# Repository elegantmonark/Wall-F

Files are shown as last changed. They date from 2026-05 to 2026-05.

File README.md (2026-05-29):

# WALL-F Waste Sorting Robot

<div align="center">

**Autonomous waste-sorting robot built for the UNSW DESN1000 ELEC stream.**

PixyCam vision | Arduino control | RGB sorting | Differential drive | Servo clamp

**2nd place out of 30 teams** with **16 successful deposits in 10 minutes**, all in the correct RGB order, earning a **High Distinction**.

[Algorithm](waste-sorting-algorithm.md) | [Wiring](wiring.md) | [Design Process](design-process.md) | [Final Report](documentation/ELEC_FinalReport_TeamC1.pdf)

</div>

## At A Glance

| Area | Details |
| --- | --- |
| Competition | UNSW DESN1000 ELEC waste-sorting robot challenge |
| Result | 2nd out of 30 teams, 16 deposits in 10 minutes, High Distinction |
| Control | Arduino-based autonomous control loop |
| Sensing | PixyCam 2.1 vision, ultrasonic obstacle sensing, IR clamp confirmation |
| Actuation | Differential drive, dual-servo clamp, deposit/reverse cycle |
| Documentation | Final report, design proposal, design journals, wiring, algorithm, calibration sketches |

## Overview

WALL-F is an autonomous waste-sorting robot designed to identify, collect, and deposit coloured balls representing different plastic waste categories inside a competition arena. The robot logs its home base colour, searches for red, green, and blue target balls in sequence, captures each ball with a front clamp, returns to base, deposits it, and repeats the cycle.

The final build used a two-level PLA chassis, a removable WALL-E-inspired shell, a PixyCam 2.1 for colour tracking, an ultrasonic sensor for obstacle detection, and an IR sensor inside the clamp for capture confirmation.

## Final Build

| Competition build | Internal layout |
| --- | --- |
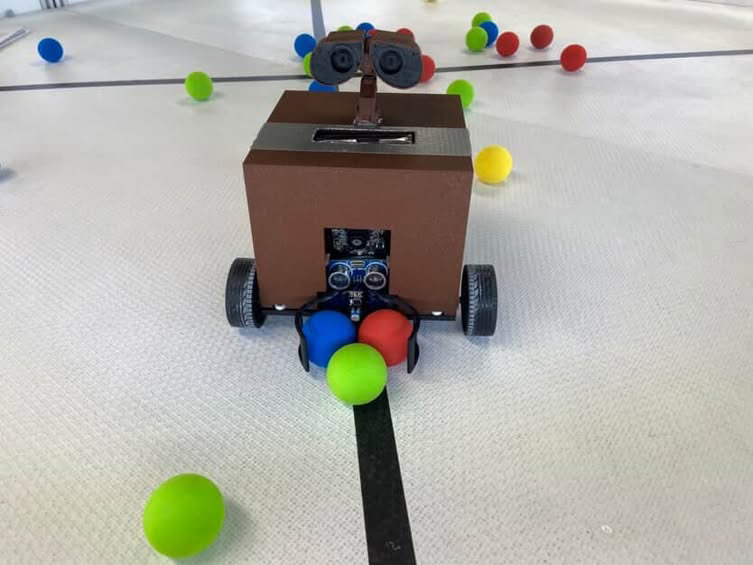
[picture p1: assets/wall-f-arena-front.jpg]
Completed WALL-F in the arena
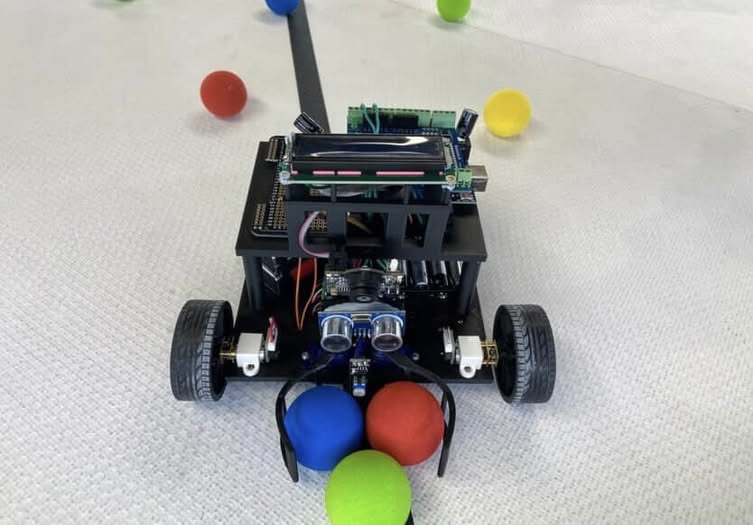
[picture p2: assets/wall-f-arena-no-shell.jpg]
WALL-F without shell showing internal layout
|  |  |

| Full assembly render | No-shell chassis |
| --- | --- |
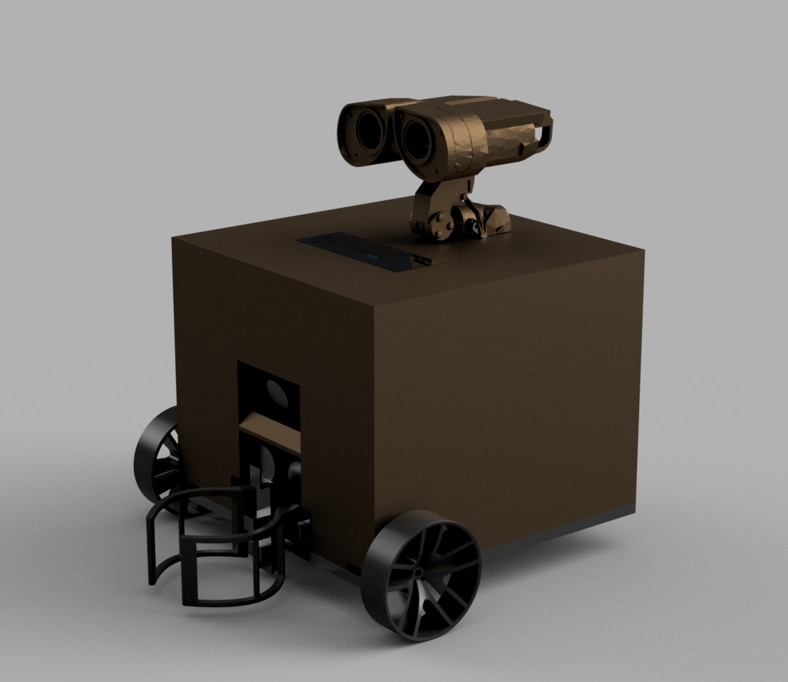
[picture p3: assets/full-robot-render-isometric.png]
WALL-F concept render
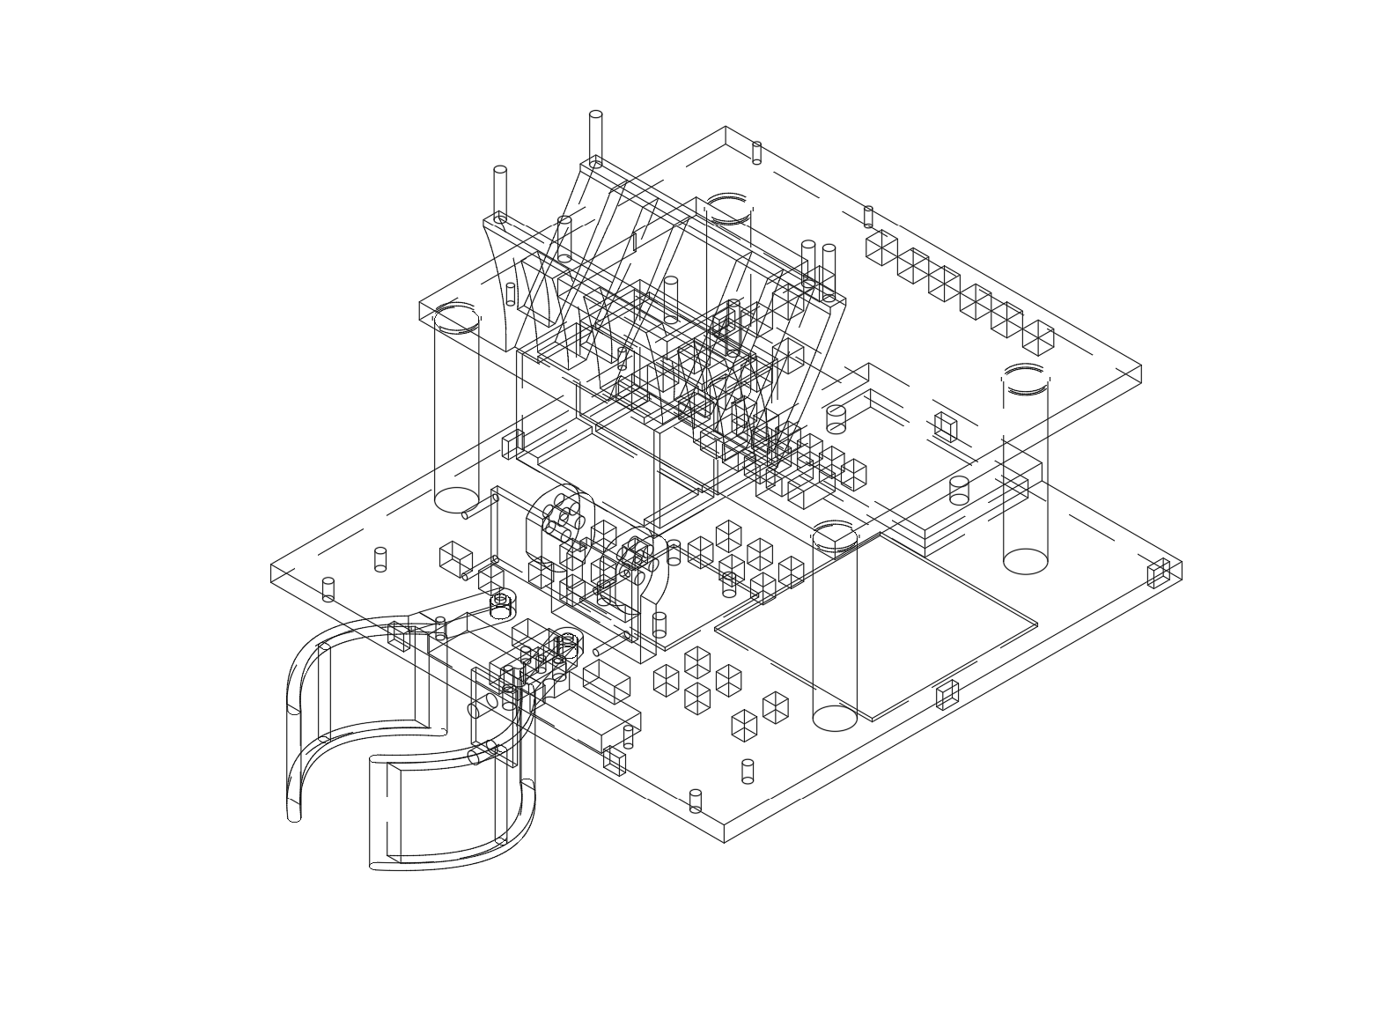
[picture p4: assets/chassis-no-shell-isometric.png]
No-shell isometric chassis model
|  |  |

## What It Does

```text
Log base -> search target -> centre -> chase -> clamp -> return -> deposit -> repeat
```

WALL-F sorts balls in strict RGB order:

```text
RED -> GREEN -> BLUE -> repeat
```

| Subsystem | Role |
| --- | --- |
| Vision | PixyCam 2.1 tracks coloured balls and home-base plates |
| Drive | Differential-drive DC motors execute calibrated movement and turning |
| Obstacle handling | HC-SR04 ultrasonic sensor detects nearby walls and obstacles |
| Capture | Dual FS90MG servos close the front clamp around a detected ball |
| Confirmation | TCRT5000 IR sensor confirms when a ball is inside the clamp |
| Deposit | Robot returns to the logged base colour, opens the clamp, reverses, and continues |

See [waste-sorting-algorithm.md](waste-sorting-algorithm.md) for the full algorithm breakdown.

## Competition Outcome

| Metric | Outcome |
| --- | --- |
| Placement | 2nd out of 30 teams |
| Deposits | 16 successful ball deposits |
| Run time | 10 minutes |
| Sequence | Correct RGB order |
| Course result | High Distinction |

## Engineering Highlights

- Built around repeated autonomous collection cycles rather than a single scripted run.
- Used PixyCam colour signatures for both target-ball tracking and home-base return.
- Combined proportional visual chasing with timed motor calibration for arena navigation.
- Integrated ultrasonic obstacle handling so the robot could recover from nearby walls.
- Used an IR-confirmed servo clamp so the robot only transitioned after a real capture.
- Debugged electrical integration issues including servo jitter caused by intermittent common-ground connection.
- Finalised an integrated RGB sequence algorithm that performed reliably during competition testing.

## Design Evolution

The design moved from early ball-retrieval concepts to a compact WALL-F gripper robot through concept scoring, mechanical iteration, sensor testing, and final integration.

Key decisions included:

- selecting a servo-actuated clamp over passive scoop and bell-enclosure concepts
- choosing a two-front-wheel and rear-caster layout for simpler turning
- separating the internal drive/sensor chassis from the removable external shell
- validating PixyCam signatures before full mechanical integration
- adding calibration sketches for motors, servos, ultrasonic sensing, IR sensing, and base return

See [design-process.md](design-process.md) for a compact public summary of the proposal, journals, and final design iteration.

## Electrical Schematic

The final circuit schematic is included as both a PNG preview and PDF exports.

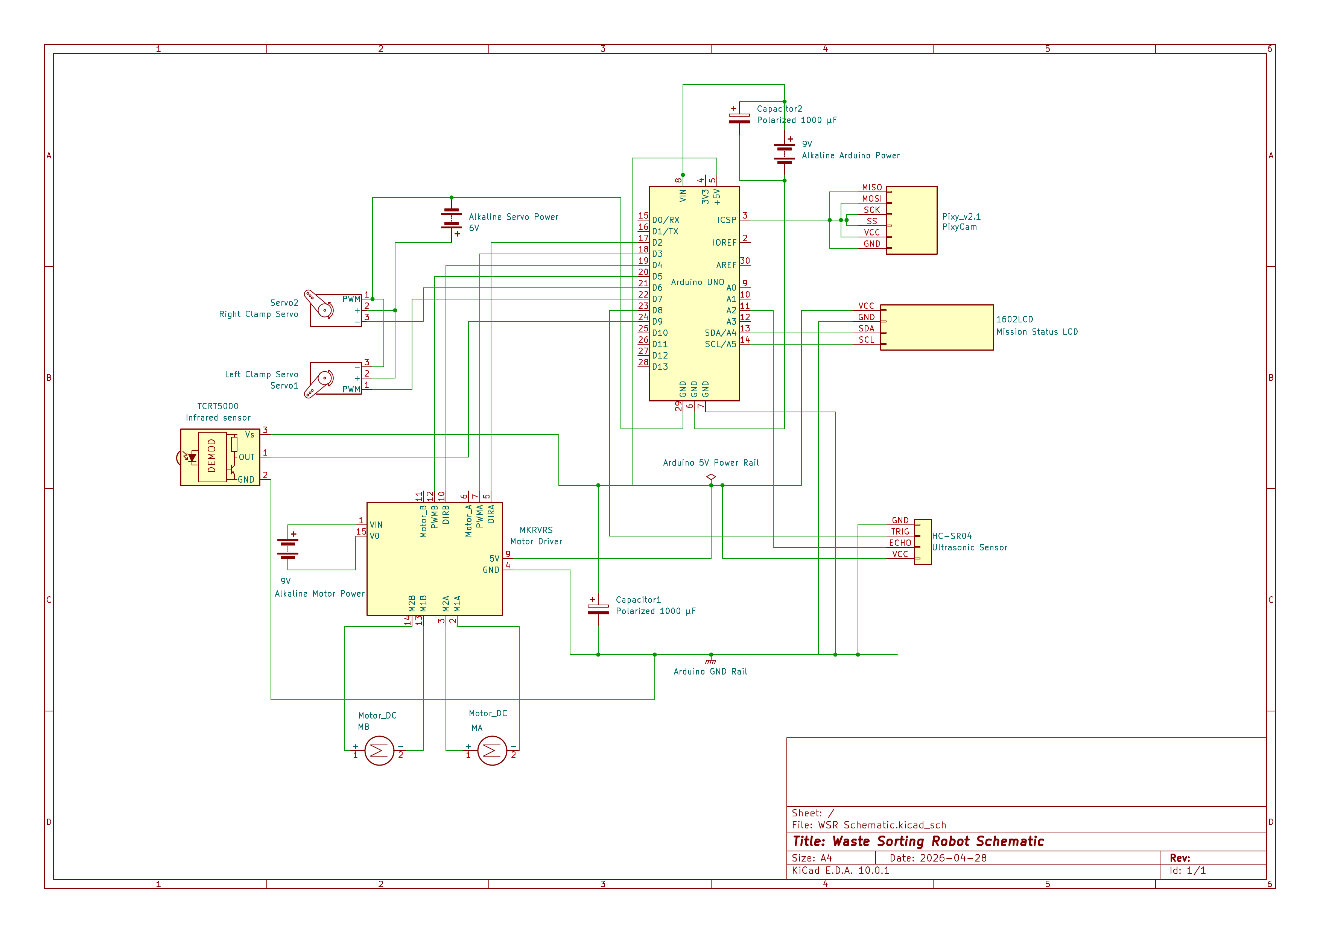
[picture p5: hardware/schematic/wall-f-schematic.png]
WALL-F final circuit schematic


| File | Purpose |
| --- | --- |
| [Schematic PNG](hardware/schematic/wall-f-schematic.png) | GitHub preview image |
| [Schematic PDF](hardware/schematic/wall-f-schematic.pdf) | Full schematic export |
| [No-drawing-sheet PDF](hardware/schematic/wall-f-schematic-no-drawing-sheet.pdf) | Cleaner schematic-only export |
| [Wiring and pin map](wiring.md) | Component wiring, pins, and power notes |

Editable KiCad files will be added under `hardware/kicad/` once exported and checked.

## Rebuild Notes

- Recalibrate PixyCam colour signatures under the lighting conditions of the new arena.
- Re-measure motor turn timing after changing batteries, wheels, floor surface, or chassis weight.
- Recheck servo open/close angles before running the full autonomous loop.
- Keep the Arduino, motor driver, sensors, and servos on a reliable common ground.

## Current Focus

WALL-F is now in public documentation mode. The main remaining upgrade is adding the editable KiCad project files once they are checked, so the repo contains the final code, schematic exports, wiring notes, calibration sketches, design process, and source hardware files in one place.

## Documentation

| Document | Purpose |
| --- | --- |
| [Final Report](documentation/ELEC_FinalReport_TeamC1.pdf) | Submitted final report with final design, evaluation, and outcome |
| [Design Proposal](documentation/Design_Proposal.pdf) | Proposal-stage concept, subsystem plan, risks, and project plan |
| [Design Journal 1](documentation/Design_Journal_1.pdf) | Early concept generation, tests, and reflections |
| [Design Journal 2](documentation/Design_Journal_2.pdf) | Later integration, compliance testing, debugging, and final iteration |
| [Design Overview](design-overview.md) | Repo-friendly summary of the final mechanical and electrical design |
| [Design Process](design-process.md) | Compact process summary derived from the proposal and design journals |
| [Visual Assets](assets/README.md) | Photos, CAD renders, and labelled subsystem images |

The public PDFs have been checked for student-number patterns. The design proposal copy excludes the original cover sheet containing student IDs.

## Repository Layout

```text
wall-f/
|-- README.md
|-- design-overview.md
|-- design-process.md
|-- waste-sorting-algorithm.md
|-- wiring.md
|-- documentation/
|   |-- ELEC_FinalReport_TeamC1.pdf
|   |-- Design_Proposal.pdf
|   |-- Design_Journal_1.pdf
|   `-- Design_Journal_2.pdf
|-- finalcode/
|   `-- FINALTESTING/
|       `-- FINALTESTING.ino
|-- calibration/
|   |-- servo-clamp-calibration/
|   |-- motor-turn-calibration/
|   |-- ultrasonic-distance-test/
|   |-- ir-clamp-test/
|   |-- pixy-signature-check/
|   `-- base-return-calibration/
|-- hardware/
|   |-- schematic/
|   `-- kicad/
`-- assets/
```

## Final Code

The final competition sketch is located at:

```text
finalcode/FINALTESTING/FINALTESTING.ino
```

The folder name matches the `.ino` file name so it can be opened directly in the Arduino IDE.

## Calibration Note

The final sketch contains the values used during the competition run. The calibration sketches use `xxxx` placeholders where values should be re-measured for a rebuilt robot, different batteries, surface friction, motor variance, or camera mounting angle.

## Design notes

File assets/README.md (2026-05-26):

# WALL-F Visual Assets

This folder contains the build photos, CAD renders, and report figures used across the WALL-F documentation.

## Real Build Photos

| Completed robot | Internal layout |
| --- | --- |
| Completed WALL-F in the arena | WALL-F without shell in the arena |

## Full Assembly

| Concept render | No-shell chassis |
| --- | --- |
| Full robot render | No-shell chassis isometric |

## Chassis Layout

| Lower level top | Lower level side |
| --- | --- |
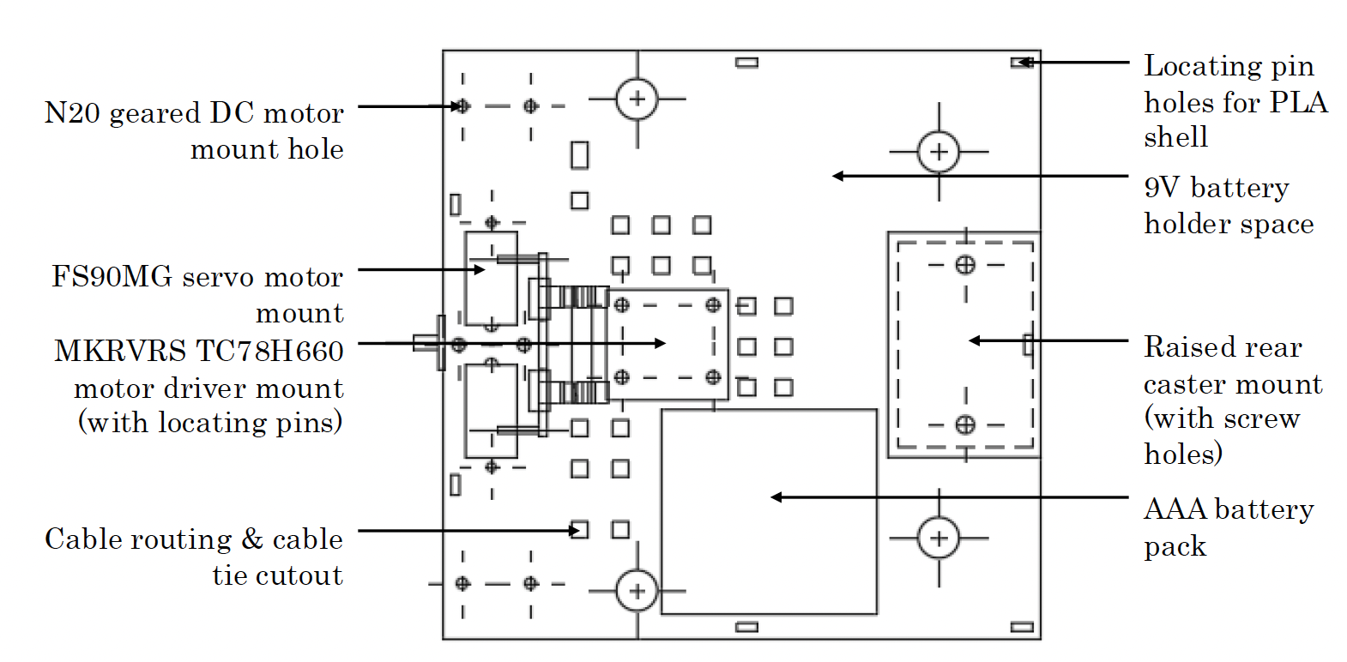
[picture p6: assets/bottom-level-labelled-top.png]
Bottom level labelled top
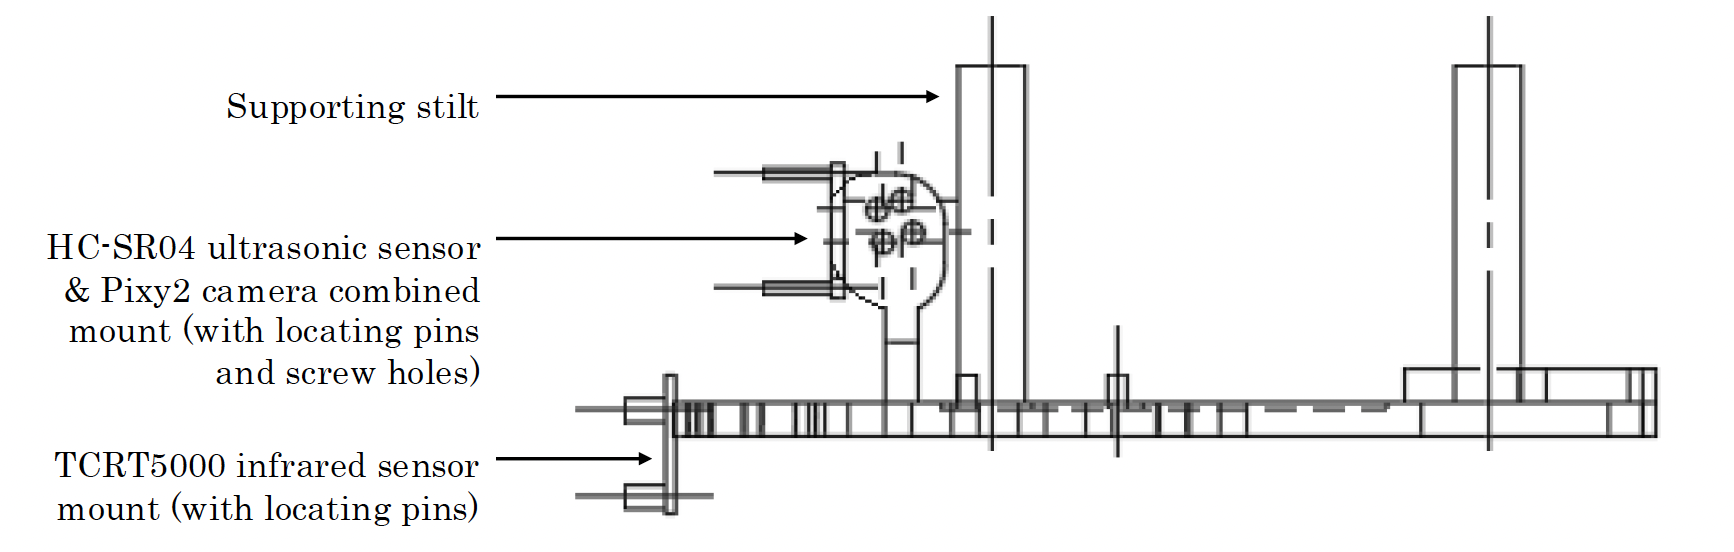
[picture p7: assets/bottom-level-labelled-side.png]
Bottom level labelled side
|  |  |

| Upper level top | Upper level side |
| --- | --- |
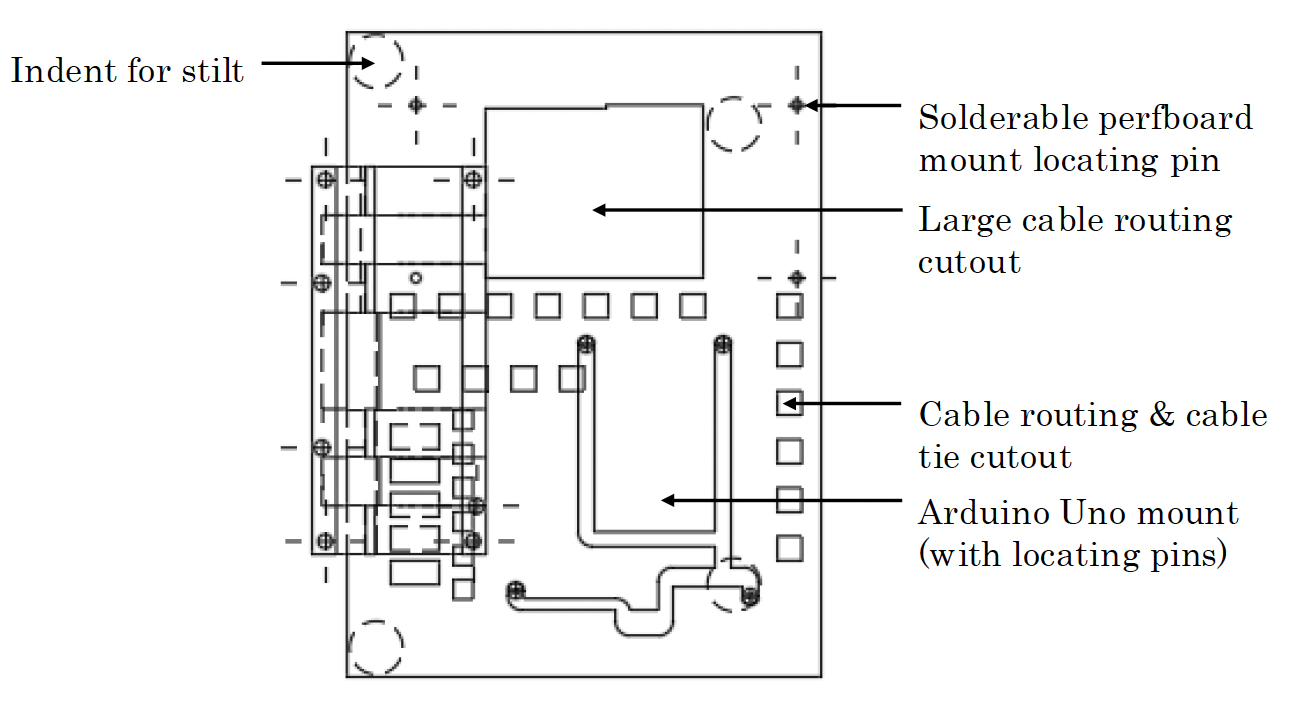
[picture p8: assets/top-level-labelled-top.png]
Top level labelled top
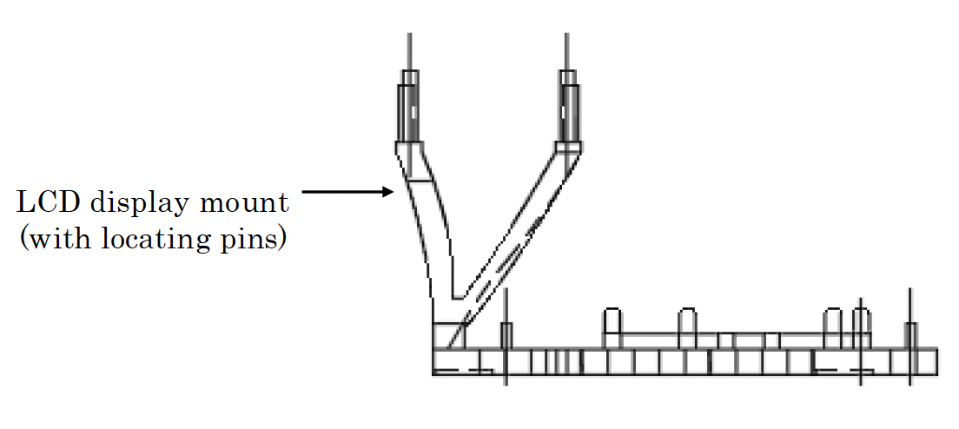
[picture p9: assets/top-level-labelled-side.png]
Top level labelled side
|  |  |

## Subsystems

| Ball collection | Sensor mount | Battery mount |
| --- | --- | --- |
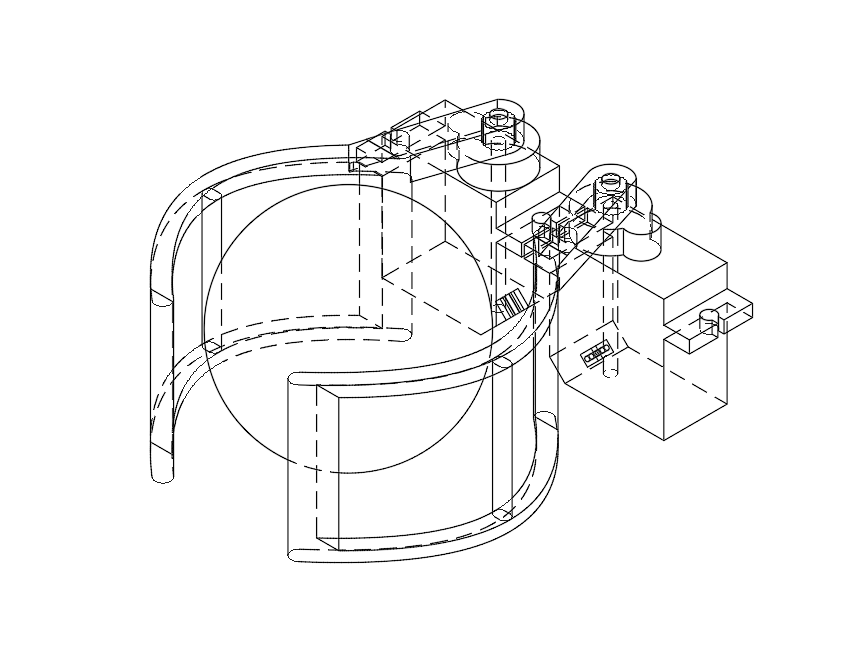
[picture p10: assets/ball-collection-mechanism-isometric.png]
Ball collection mechanism
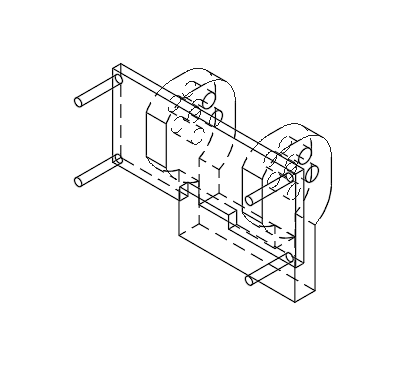
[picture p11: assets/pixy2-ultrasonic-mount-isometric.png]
PixyCam and ultrasonic mount
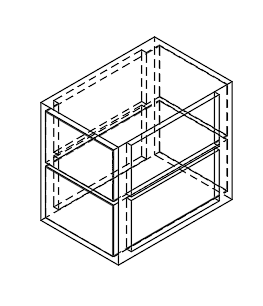
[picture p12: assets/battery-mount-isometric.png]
Battery mount
|  |  |  |

| Wheel side | Wheel front |
| --- | --- |
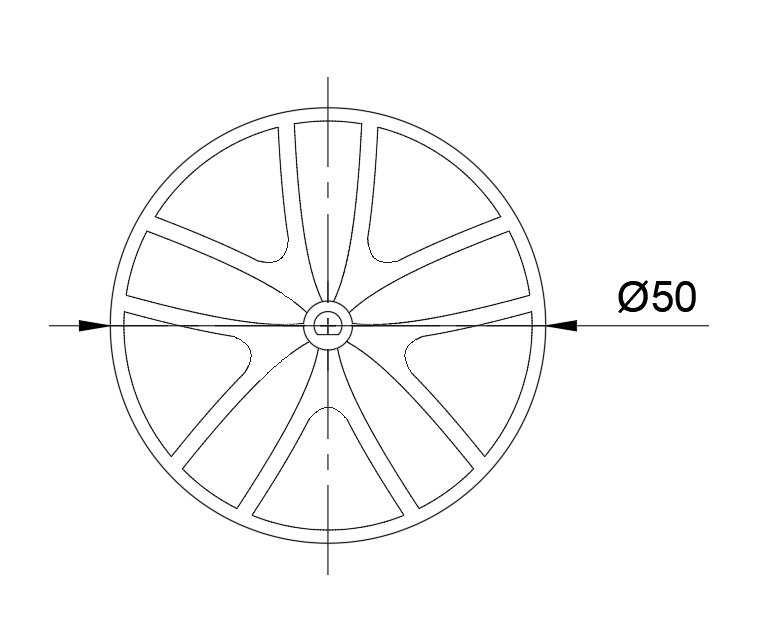
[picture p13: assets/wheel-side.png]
Wheel side view
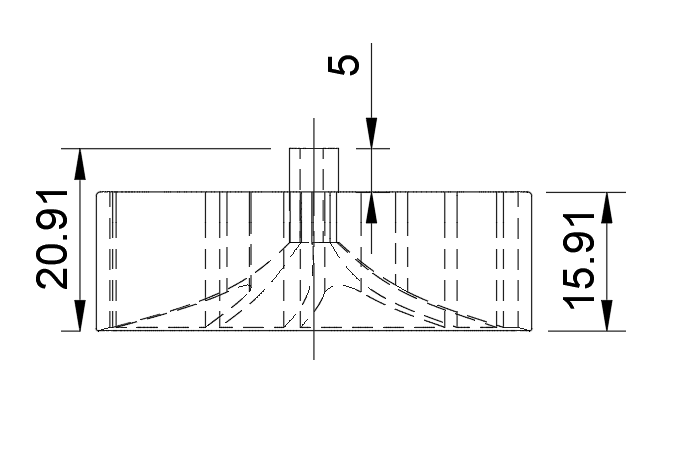
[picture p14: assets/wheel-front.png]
Wheel front view
|  |  |

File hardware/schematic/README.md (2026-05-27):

# WALL-F Electrical Schematic

This folder contains the final WALL-F circuit schematic used by the wiring documentation.

## Preview

WALL-F final circuit schematic

## Files

- `wall-f-schematic.png` - PNG schematic preview embedded in the repo documentation.
- `wall-f-schematic.pdf` - full schematic PDF export.
- `wall-f-schematic-no-drawing-sheet.pdf` - schematic-only PDF export without the drawing sheet.

Editable KiCad project files will be added under `../kicad/` once they are exported and checked.

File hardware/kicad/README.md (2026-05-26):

# KiCad Source Files

Editable KiCad source files for the WALL-F schematic will be placed here once they are exported and checked.

The checked source should match:

- `../schematic/wall-f-schematic.png`
- `../../wiring.md`
- `../../finalcode/FINALTESTING/FINALTESTING.ino`

Until those files are added, the published schematic reference is available in `../schematic/`.

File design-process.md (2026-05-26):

# WALL-F Design Process

This document condenses the design proposal and design journals into a repo-friendly summary of how WALL-F evolved from early concepts into the final competition robot.

## 1. Problem Framing

The project goal was to build a self-contained autonomous robot that could sort coloured balls representing plastic waste categories inside a defined arena. The robot needed to identify target colours, avoid non-target material, collect balls, return to its base, and deposit in the required order.

The main engineering constraints were:

- Fit within a 200 mm x 200 mm x 200 mm size envelope.
- Use the provided DESN1000 kit plus limited additional materials.
- Operate autonomously during testing.
- Reliably detect coloured balls and base plates.
- Handle repeated collection cycles within a 10-minute run.

## 2. Early Concept Exploration

The team explored several ball-retrieval and chassis concepts before committing to the final architecture:

- Passive funnel scoop with internal storage.
- Descending bell/enclosure mechanism.
- Servo-actuated clamp around the target ball.
- Three-wheel layout with a rear caster.
- Four-wheel layout for stability.
- WALL-E-inspired tank-track style concept.

The servo clamp and rear-caster layout became the most practical direction because it kept the mechanism simple, controllable, and easier to calibrate within the project timeline.

## 3. Sensor And Subsystem Development

Early work focused on validating the sensing stack before full robot integration.

- PixyCam colour signatures were tested against red and green sample balls before the final foam balls were available.
- HC-SR04 ultrasonic distance sensing was simulated and then physically tested.
- TCRT5000 IR sensing was evaluated for close-range ball capture confirmation.
- Servo sweep tests established the usable 0-180 degree range for the clamp mechanism.

These tests shaped the final sensor placement: PixyCam and ultrasonic at the front, with the IR sensor positioned inside the clamp region.

## 4. Compliance Testing Pivot

During compliance-test planning, the team compared subsystem demonstration options. The perception/navigation path was selected as the most realistic route because the PixyCam colour signatures, motor driver, and ultrasonic obstacle logic were already progressing.

This decision pushed development toward:

- base recognition,
- obstacle detection,
- PixyCam-guided centring,
- calibrated motor movement,
- LCD status feedback,
- and a repeatable navigation loop.

## 5. Mechanical Iteration

The robot moved from early sketches and isolated tests into a two-level PLA chassis.

Important mechanical decisions:

- Two front drive wheels with a rear caster for manoeuvrability.
- A two-level chassis separating drive/power-heavy components from control electronics.
- A front clamp shaped around the fixed ball size used in the arena.
- A removable WALL-E-inspired shell for final presentation.
- A dedicated battery mount to reduce battery movement during turns.

In testing, the rear caster improved turning consistency compared with earlier assumptions that could have been compensated for incorrectly in software.

## 6. Electrical And Integration Debugging

The final electrical architecture used separate power rails for the Arduino, motors, and servos while tying all grounds together.

Key integration lessons:

- Servo jitter was traced to an intermittent common-ground connection.
- The I2C LCD reduced pin pressure on the Arduino Uno.
- PixyCam SPI pins constrained the remaining sensor pin assignments.
- Large capacitors were added for transient smoothing.
- Servo power was separated from the Arduino 5 V rail to avoid brownouts.

These changes made the final robot more stable during repeated motor and clamp actuation.

## 7. Algorithm Evolution

The final software evolved from component tests into a repeated mission cycle:

```text
Log base -> search target -> centre -> chase -> clamp -> return -> deposit -> repeat
```

Important algorithmic choices:

- Log the home base before leaving it.
- Use strict RGB target ordering.
- Centre targets using PixyCam x-position error.
- Slow down as the target block grows larger.
- Confirm capture using the clamp IR sensor.
- Use ultrasonic obstacle handling during general navigation.
- Suppress obstacle handling while intentionally approaching the base.
- Use base apparent size to estimate return arrival.

The final sketch is documented in [waste-sorting-algorithm.md](waste-sorting-algorithm.md).

## 8. Final Outcome

The final competition robot completed 16 successful deposits in 10 minutes, deposited balls in the correct RGB sequence, placed 2nd out of 30 teams, and earned a High Distinction result.

The result came from the combined reliability of the PixyCam tracking, calibrated movement, clamp capture confirmation, obstacle handling, and return-to-base logic.

## Source Documents

- [Design Proposal](documentation/Design_Proposal.pdf)
- [Design Journal 1](documentation/Design_Journal_1.pdf)
- [Design Journal 2](documentation/Design_Journal_2.pdf)
- [Final Report](documentation/ELEC_FinalReport_TeamC1.pdf)

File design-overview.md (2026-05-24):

# WALL-F Design Overview

This overview summarises the final WALL-F waste-sorting robot design using the key figures from the project report and build photos.

## 1. Final Robot

WALL-F was built as a compact autonomous robot for the ELEC stream of UNSW DESN1000. The robot operates inside a defined arena, identifies coloured balls using a PixyCam 2.1, collects them with a front clamp, and returns them to a logged home base.

Completed WALL-F robot operating in the arena

The completed robot uses a removable outer shell inspired by WALL-E. The shell protects the internal electronics while leaving openings for the LCD, PixyCam, ultrasonic sensor, and front clamp.

WALL-F concept render

## 2. Chassis Architecture

The robot is arranged around a two-level PLA chassis. The lower level carries the drive system, batteries, sensors, clamp, and motor driver. The upper level carries the Arduino Uno, shield, perfboard, and LCD.

WALL-F without shell in the arena

The no-shell isometric model shows the internal component layout and the relationship between the clamp, sensor mount, lower chassis, and upper electronics platform.

No-shell chassis isometric model

## 3. Lower Level

The lower level contains the mechanical and power-heavy components: the two front drive motors, wheels, batteries, motor driver, clamp servos, PixyCam, HC-SR04 ultrasonic sensor, and TCRT5000 IR sensor.

| Lower level top view | Lower level side view |
|---|---|
| Bottom level labelled top view | Bottom level labelled side view |

The lower chassis also includes cable routing cutouts and mounting features to keep wiring traceable and reduce movement during operation.

## 4. Upper Level

The upper level carries the main control electronics and user feedback hardware. The LCD is mounted on top so the robot can display its current mission state during testing and operation.

| Upper level top view | Upper level side view |
|---|---|
| Top level labelled top view | Top level labelled side view |

Separating the control electronics from the lower drive components helped keep the layout compact while preserving access for debugging and maintenance.

## 5. Ball Collection Mechanism

The ball handling subsystem uses two FS90MG servos and a pair of curved clamp arms. The clamp remains open while the robot approaches a target ball, then closes once the TCRT5000 IR sensor detects that a ball has entered the clamp region.

Ball collection mechanism isometric model

The clamp is intentionally simple: it is shaped around the fixed ball size used in the DESN1000 arena rather than designed as a general-purpose gripper.

## 6. Sensor Mounting

The PixyCam 2.1 and HC-SR04 ultrasonic sensor are mounted together at the front of the robot. The PixyCam tracks coloured balls and base plates, while the ultrasonic sensor detects obstacles in the robot's forward path.

PixyCam and ultrasonic mount isometric model

The camera mount angle is calibration-dependent. In the final build, the camera was angled downward so nearby balls, the clamp region, and base plates remained visible during approach.

## 7. Drive And Stability

The robot uses two front drive wheels and a rear caster wheel. Differential drive allows it to move forward, reverse, and turn on the spot.

| Wheel side view | Wheel front view |
|---|---|
| Wheel side view | Wheel front view |

Rubber tyres were added to improve traction and turning accuracy compared with bare PLA wheels.

The final design also added a dedicated battery mount to stop the 9 V batteries shifting during movement, which improved steering consistency.

Battery mount isometric model

## 8. Electrical System

The final electrical design uses separate supplies for the Arduino, motors, and servos, with a shared common ground. This reduced brownouts and improved reliability during motor and servo current spikes.

WALL-F circuit diagram

The final circuit used:

- 9 V alkaline battery for Arduino input.
- 9 V alkaline battery for the MKRVRS motor rail.
- 4xAAA alkaline battery pack for the servo rail.
- Common ground between all modules.
- 1000 uF capacitors for transient smoothing.

The detailed pin map and power notes are documented in `wiring.md`.

## 9. Software Integration

The final Arduino sketch coordinates all subsystems through a repeated mission loop:

```text
Log base -> search target -> centre -> chase -> clamp -> return -> deposit -> repeat
```

The robot collects balls in the strict order:

```text
RED -> GREEN -> BLUE -> repeat
```

Further details are documented in `waste-sorting-algorithm.md`.

## 10. Final Testing Outcome

During the 10-minute final testing run, WALL-F completed 16 successful ball deposits and placed 2nd overall. The result showed that the combined vision, clamp, obstacle handling, and return-to-base behaviours were reliable enough for repeated autonomous sorting cycles under competition conditions.

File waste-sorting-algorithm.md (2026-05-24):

# WALL-F Waste Sorting Algorithm

This document describes the algorithm implemented in `finalcode/FINALTESTING/FINALTESTING.ino`.

## Colour Signatures

The PixyCam 2.1 is used in Colour Connected Components mode.

| Signature | Meaning |
|---:|---|
| 1 | Red ball |
| 2 | Green ball |
| 3 | Blue ball |
| 4 | Orange base |
| 5 | Yellow base |
| 6 | Pink base |
| 7 | Purple base |

The main loop runs the collection order:

```text
RED -> GREEN -> BLUE -> repeat
```

## Startup Sequence

1. Configure motor, ultrasonic, IR, servo, LCD, and PixyCam interfaces.
2. Stop both motors.
3. Attach both clamp servos.
4. Open the clamp to establish a known mechanical state.
5. Initialise the LCD and PixyCam.
6. Keep the PixyCam lamp off.
7. Scan for the home base before moving.
8. Store the detected base signature, width, height, and area.
9. Reverse briefly away from the base.
10. Enter the repeating mission loop.

The base is logged before movement so the robot knows which colour plate to return to after collecting a ball.

## One Colour Cycle

Each colour cycle is handled by `doOneColourCycle(...)`.

1. Display the target colour on the LCD.
2. Open the clamp.
3. If the robot is still facing the base, turn 180 degrees to face the arena.
4. Perform an initial 180-degree sweep for the target ball.
5. If the target is not found, drive forward briefly.
6. Search until the target signature is found.
7. Centre on the target using PixyCam x-position.
8. Chase the target using proportional steering.
9. Confirm capture with the clamp IR sensor.
10. Close the clamp.
11. Search for the logged home base.
12. Centre on the base.
13. Drive toward the base until its apparent PixyCam size reaches the stored startup reference.
14. Inch forward for the deposit.
15. Open the clamp to release the ball.
16. Reverse away from the base.
17. Turn 180 degrees back toward the arena.
18. Continue to the next colour.

## Search Behaviour

The search routine is forward-biased. The robot first checks whether the target is already visible. If not, it drives forward in short steps while repeatedly checking the PixyCam.

At intervals, it performs a 180-degree sweep. If multiple sweeps fail, it escalates to a full sweep using the configured `TURN_360_MS` timing. These turn timings are calibration-dependent and should be re-measured if the robot is rebuilt.

## Chase Behaviour

The chase routine uses proportional steering from the target's horizontal position in the PixyCam frame:

```text
error = target_x - frame_center_x
correction = STEER_KP * error
left_pwm = base_speed + correction
right_pwm = base_speed - correction
```

When the target block appears large, the robot slows down to approach more carefully. If the target is lost briefly, the robot rotates toward the side where it was last seen. If it remains lost, it performs local sweep recovery.

## Capture Behaviour

The clamp starts open. During chase, the TCRT5000 IR sensor checks whether a ball has entered the clamp area.

The code assumes the IR sensor is active LOW:

```text
LOW = ball detected
HIGH = no ball detected
```

Once a ball is detected, the robot stops and closes both servos around the ball.

## Obstacle Behaviour

Obstacle detection uses the HC-SR04 ultrasonic sensor with median filtering. The current competition threshold is 10 cm.

If an obstacle is detected during normal navigation:

1. Stop.
2. Wait up to 3 seconds for the path to clear.
3. If clear, resume the current task.
4. If still blocked, reverse slightly.
5. Perform a 360-degree target scan.
6. If the target is not found, turn 180 degrees and drive forward briefly.
7. Resume search.

Obstacle handling is suppressed while intentionally approaching the home base. Otherwise, the base itself would be treated as an obstacle.

## Return And Deposit

After capture, the robot searches for the base signature recorded during startup. It performs a full sweep until the base is found, centres on it, then approaches using the same PixyCam proportional steering style.

Arrival is estimated from the base's apparent size. The robot compares the current base block width, height, and area against the stored startup values.

Once arrival is detected:

1. Stop.
2. Inch forward for a calibrated time.
3. Open the clamp.
4. Reverse away from the base.
5. Turn 180 degrees toward the arena.
6. Mark itself as facing the arena for the next cycle.

## Calibration-Dependent Values

The final competition sketch contains real tested values, but these should be recalibrated for a rebuilt robot:

- Servo open and closed angles
- 90-degree, 180-degree, and 360-degree turn timings
- Forward, approach, inching, and turning PWM values
- PixyCam centre x-position and centring deadband
- Base return size thresholds
- Deposit inch-forward time
- Obstacle threshold and reverse timing

See the `calibration/` folder for placeholder sketches.

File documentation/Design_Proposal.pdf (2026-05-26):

## Executive Summary

This project aims to develop an autonomous robot that sorts coloured balls, representing different plastic types, into their correct categories within a defined arena. Accordingly, this report presents the design team’s understanding of the problem the project addresses, explains the chosen design in detail, and outlines associated risks and their management strategies. It also includes a detailed project plan and Gantt chart to support the successful completion of the robot.

The proposed design for the project is a Wall-E inspired robot based on a PLA chassis. Key design features include two front drive wheels and a rear ball caster wheel for mobility as well as an Arduino Uno microcontroller for autonomous control. It also features multiple batteries for power and several sensors to detect balls and bases and obstacles. To collect balls, the robot moves towards a target ball and aligns it with its clamps. These then close and the robot returns to base to deposit the ball. During development, emphasis was placed on making the design simple, reliable, affordable, and easy to modify. A subsystem breakdown was used, which allowed each part of the robot to be developed simultaneously and adjusted easily.

However, the design is limited in scope and application. It is highly specialised for ball collection within a controlled arena and cannot be applied directly to plastic waste sorting without significant modification. Additionally, the robot’s batteries do not provide sufficient capacity for continuous operation over several hours, restricting its practicality in real-world applications.

Overall, it is anticipated that the project will be completed by the deadline of 23 April 2026 and that all required objectives will be achieved.

ii

## Contents

1 Introduction | 1
2 Design Concept | 1
3 Relevant Knowledge | 4
4 Risk Management | 11
5 Project Plan | 12
6 Conclusion | 14
7 References | 14
8 Appendices | 16

iii

## List of Figures

1 | Technical drawing of the overall robot design | | 1
2 | Block diagram of the subsystems and their interactions | | 2
3 | Technical drawing of clamp mechanism | | 4
4 | Diagram of Arduino Uno pin connections | | 5
5 | Code excerpt of median filter implementation using bubble sort | | 6
6 | Code excerpt of the time jitter technique | | 7
7 | Diagram of H-bridge circuit | | 8
8 | Flowchart of the ball collection and deposit algorithm | 10

## List of Tables

1 | Arduino Uno pin connections | | 5

iv

## 1 Introduction

The purpose of this report is to present and explain the proposed design of the prototype waste sorting robot, as well as identify key project risks and outline the project timeline.

On university campuses and in public environments, plastic waste is often sorted improperly. When different types of plastic are incorrectly sorted together, they cannot be recycled and must instead be sent to landfill. As the volume of plastic waste produced worldwide continues to rise, manual sorting becomes increasingly unsuitable to address this problem [1]. Autonomous wast sorting technologies offer a solution by providing faster, more accurate, and cost-effective sorting [1].

The design problem of this project is therefore to develop a prototype of an autonomous robot that navigates and accurately sorts plastic waste, represented by coloured balls, into PET, HDPE, and PP categories. The robot must identify and avoid non-recyclable materials, represented by yellow balls. It must also be self-contained with maximum dimensions of 200 mm × 200 mm × 200 mm and use no more than $50 in additional materials beyond the provided kit. The project must be completed and ready to test by 23 April 2026.

The format of this report is as follows. First, the Design Concept section provides a system overview, summarises how each component works and interfaces with others to achieve the design objectives, and outlines the team’s consideration of alternative designs. Second, the Relevant Knowledge section provides in-depth technical explanations of how each subsystem functions and interacts to form the complete system. Third, the Risk Management section identifies risks and outlines mitigation strategies and backup plans. Fourth, the Project Plan section presents a Gantt chart showing task breakdowns, deadlines, and task assignments, with justification for the schedule. Finally, the Conclusion summarises the key findings and outcomes of the report.

## 2 Design Concept

### 2.1 System Overview

The proposed design is an autonomous, Wall-E-inspired robot that sorts coloured balls representing different types of plastic waste into their correct categories. The overall design of the robot is shown in Figure 1.

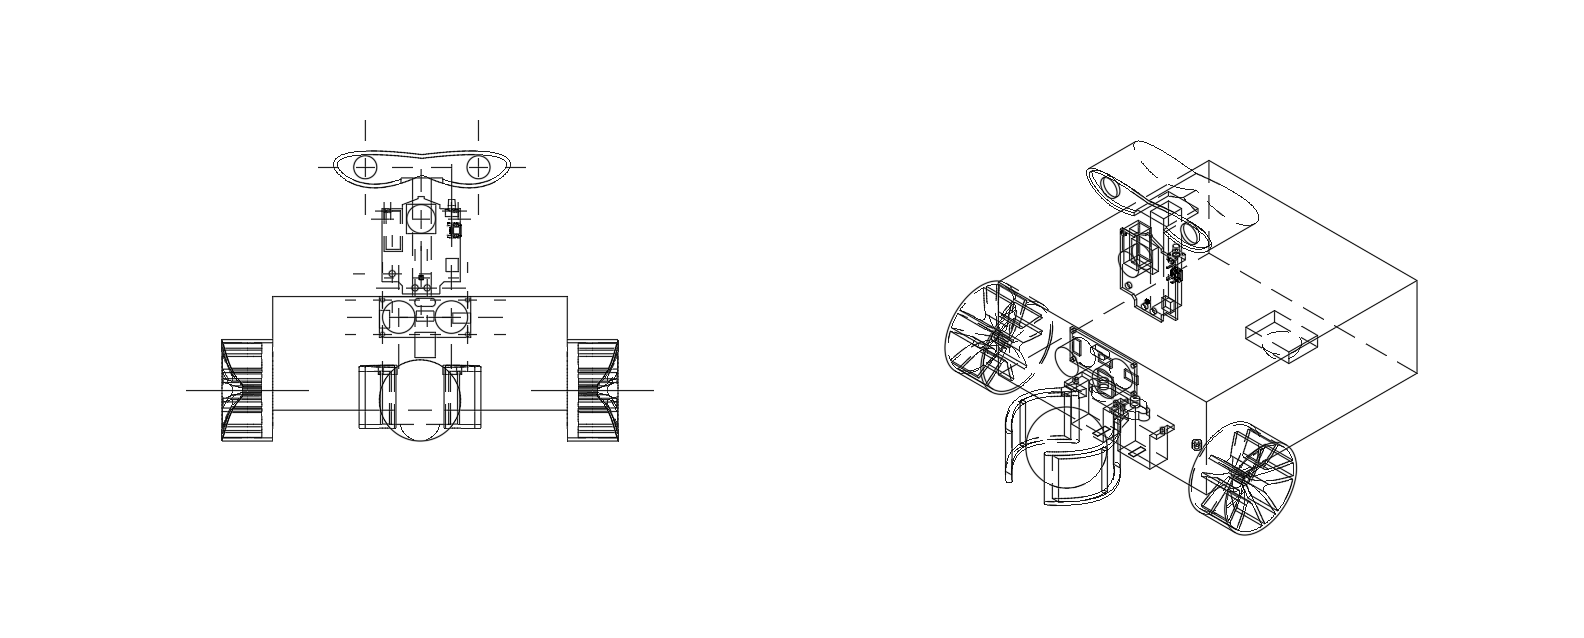
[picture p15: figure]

Figure 1: Technical drawing of the overall robot design

To achieve the project objectives, the robot has been divided into four distinct subsystems. This modular approach enables independent development of each subsystem and allows modifications without completely redesigning the robot. The four subsystems are:

- Control Subsystem
- Vision and Detection Subsystem
- Chassis and Navigation Subsystem
- Ball Handling Subsystem

Figure 2 illustrates the basic interactions between subsystems. Further detailed explanations of these interactions are provided throughout the Relevant Knowledge section.

Vision and Detection
Subsystem

Control
Subsystem

Chassis and
Navigation
Subsystem

Ball Handling
Subsystem

Sensor Data

Movement
Commands

Actuation
Commands

Figure 2: Block diagram of the subsystems and their interactions

### 2.2 Subsystem Specifications

### 2.2.1 Control Subsystem

The Control Subsystem is responsible for managing the operation of the entire robot. It receives sensor data from the Vision and Detection Subsystem, which it uses to send movement commands to the Chassis and Navigation Subsystem and actuation commands to the Ball Handling Subsystem. This coordination thereby enables the robot to autonomously navigate, collect, and sort the balls.

The Control Subsystem consists of an Arduino Uno microcontroller [2]. This component was selected for its affordability and simple interfacing via input-output pins. These pins enable easy connection and control of all motors, servos, and sensors across the system.

### 2.2.2 Vision and Detection Subsystem

The Vision and Detection Subsystem is responsible for gathering information about the robot’s surroundings. It identifies coloured balls and base, measures distance to obstacles, and detects when a ball enters the clamp, sending this data to the Control Subsystem. This sensory data enables the robot to navigate towards target balls or base, avoid obstacles, and actuate the clamp accurately.

The Vision and Detection Subsystem consists of a Pixy2 camera, an HC-SR04 ultrasonic sensor, and an FC-51 infrared sensor. The Pixy2 was selected for its built-in colour tracking and simple training process. It detects different coloured balls and bases, sending position data to the Arduino which commands the motors to move towards target balls or return to base. The ultrasonic sensor measures distance to obstacles, sending this data to the Arduino which commands the motors to brake when obstacles are too close. The IR sensor detects balls in the clamp zone, sending this data to the Arduino which commands the servos to open or close the clamp.

### 2.2.3 Chassis and Navigation Subsystem

The Chassis and Navigation Subsystem is responsible for providing structural support for all components and physically moving the robot throughout the arena. It receives movement commands from the Control Subsystem to control motors, enabling the robot to navigate towards target balls, return to base, and avoid obstacles.

The Chassis and Navigation Subsystem consists of a 3D-printed PLA chassis, an MKRVRS TC78H660 motor driver, two DC motors, two front wheels, and one rear ball caster wheel. The PLA chassis was selected for its strength and light weight, which aids manoeuvrability whilst supporting all components securely. The chassis has two levels to mount all components. The MKRVRS motor driver independently controls both DC motors by varying their speed and direction or applying braking. This enables the robot to move forward, move backward, turn, and stop precisely. The DC motors convert electrical signals from the motor driver into rotational force, which drives the front wheels to move the robot. The rear ball caster wheel provides a low-friction pivot point, enabling the robot to rotate on the spot for precise positioning during ball collection and deposit.

### 2.2.4 Ball Handling Subsystem

The Ball Handling Subsystem is responsible for collecting and releasing balls during operation. It receives actuation commands from the Control Subsystem to control the clamp mechanism, enabling the robot to collect balls and deposit them at base.

The Ball Handling Subsystem consists of two servo motors and 3D-printed clamp arms. The servo motors were selected for their precise angular control and simple interfacing with the Arduino. Actuation commands from the Arduino trigger the servos to rotate the clamp arms to open or close positions, creating or releasing the grip on a ball. The clamp arms were designed with a curved shape to enclose a ball securely. A technical drawing of the clamp mechanism is shown in Figure 3.

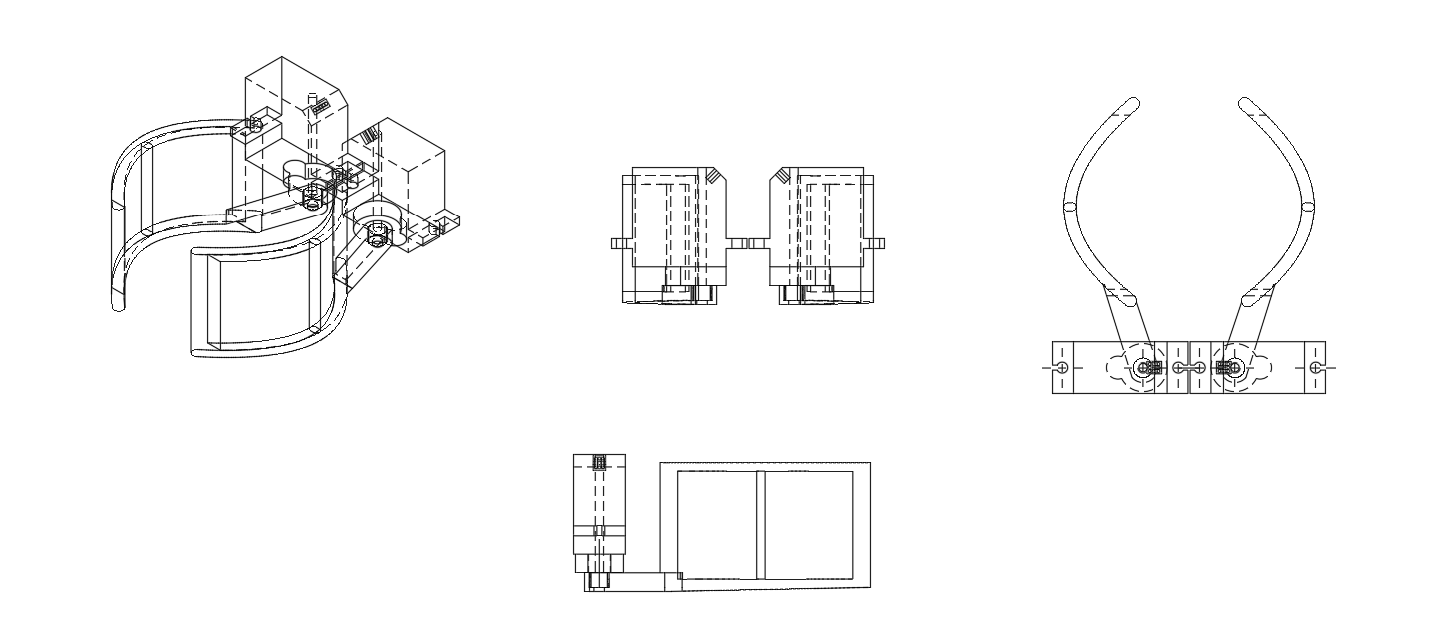
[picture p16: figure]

Figure 3: Technical drawing of clamp mechanism

### 2.3 Consideration of Alternative Designs

To select the final design for each subsystem and the overall robot, the team considered several alternative designs. A morphological chart was developed to organise and compare all the design concepts systematically. Using this approach, the team could evaluate and assess how well different concepts would work together. Based on this analysis, the most promising options were selected. Additionally, the morphological chart serves as a reference tool, allowing the team to revisit alternative solutions if a chosen approach proves unfeasible. The complete morphological chart is provided in Appendix A.

## 3 Relevant Knowledge

### 3.1 Control Subsystem

### 3.1.1 Power Supply

The Arduino is powered by a 9V lithium polymer battery connected through a barrel jack. The onboard voltage regulator converts the 9V input to 5V, which powers the microcontroller and provides regulated voltage to other connected components.

### 3.1.2 Sensor Inputs and Decision Logic

The Arduino receives sensor data from three components in the Vision and Detection Subsystem. The Pixy2 camera identifies coloured balls and bases using its built-in Colour Connected Components algorithm. Additionally, the HC-SR04 ultrasonic sensor measures distance to obstacles, and the FC-51 infrared sensor detects when a ball enters the clamp. The Arduino processes this sensor data using conditional logic in the code to determine commands. This loop continuously repeats by reading sensor inputs, evaluating conditions, and sending commands to the Chassis and Navigation Subsystem or the Ball Handling Subsystem.

### 3.1.3 Control Outputs

The Arduino sends commands to other subsystems using Pulse Width Modulation (PWM) signals [3]. PWM controls average voltage by adjusting the duty cycle, which is the proportion of time that a square wave signal stays high. For the MKRVRS motor driver, a higher duty cycle produces a higher average voltage, resulting in faster motor rotation. For servo motors, the pulse width determines the rotation angle, and the Arduino sends continuous signals to maintain the desired position.

### 3.1.4 Connection Diagram

Figure 4 and Table 1 show the pin connections between the Arduino and all the robot components.

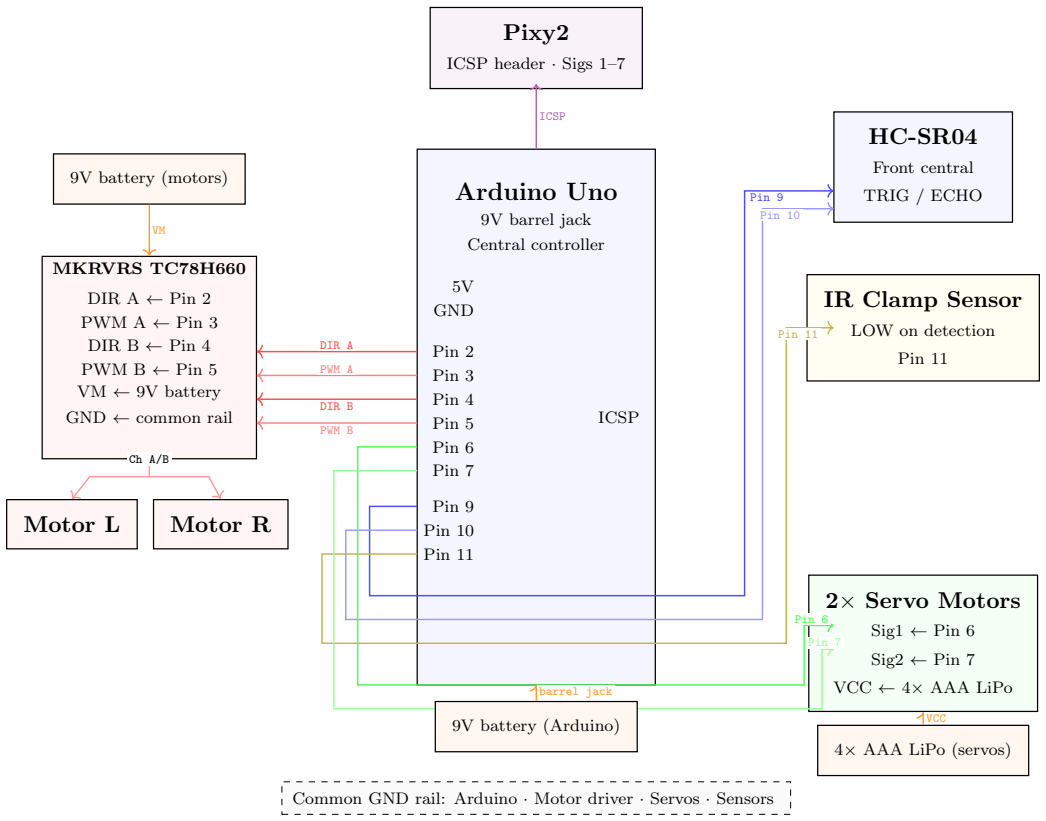
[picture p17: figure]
Arduino Uno; 9V barrel jack; Central controller; GND; Pin 2; Pin 3; Pin 4; Pin 5; Pin 6; Pin 7; Pin 9; Pin 10; Pin 11; ICSP; MKRVRS TC78H660; DIR A ← Pin 2; PWM A ← Pin 3; DIR B ← Pin 4; PWM B ← Pin 5 VM ← 9V battery; GND ← common rail; DIR A; PWM A; DIR B; PWM B; 9V battery (motors); Motor L; Motor R; Pixy2; ICSP header · Sigs 1–7; Front central; TRIG / ECHO; IR Clamp Sensor; LOW on detection; 2× Servo Motors; Sig1 ← Pin 6; Sig2 ← Pin 7; VCC ← 4× AAA LiPo; 4× AAA LiPo (servos); VCC 9V battery (Arduino); barrel jack

Common GND rail: Arduino · Motor driver · Servos · Sensors

Figure 4: Diagram of Arduino Uno pin connections

Pin | Component | Function | Direction
ICSP | Pixy2 | SPI data + power | Bidirectional
2 | MKRVRS TC78H660 | DIR A | Output
3 | MKRVRS TC78H660 | PWM A | Output
4 | MKRVRS TC78H660 | DIR B | Output
5 | MKRVRS TC78H660 | PWM B | Output
6 | Servo 1 | Signal | Output
7 | Servo 2 | Signal | Output
9 | HC-SR04 | TRIG | Output
10 | HC-SR04 | ECHO | Input
11 | IR clamp sensor | Ball detect (LOW) | Input

Table 1: Arduino Uno pin connections

### 3.2 Vision and Detection Subsystem

### 3.2.1 Pixy2 Camera Operation

The Pixy2 detects coloured objects using trained colour signatures in Colour Connected Components mode [4]. Signatures 1 to 3 identify red, green, and blue balls respectively, while signatures 4 to 7 identify the four corner bases. The camera stores base colour signatures at startup. When an object is detected, the Pixy2 reports its position as X–Y coordinates and signature pixel size [5]. The camera communicates with the Arduino via SPI protocol through the ICSP pins [6], where the Arduino requests or receives data. The Pixy2 receives 5V power through the ICSP pins.

### 3.2.2 HC-SR04 Ultrasonic Sensor Operation

The HC-SR04 measures distance using 40 kHz ultrasonic sound waves [7]. The Arduino sends a trigger signal to the sensor, which causes it to emit a short ultrasonic burst. This sound wave travels forward until it hits an obstacle and reflects back. The sensor detects the returning echo and measures how long the pulse was absent. The Arduino then calculates the distance using this time measurement. The sensor receives 5V power from the Arduino’s 5V output pin.

The ultrasonic sensor can output inaccurate readings due to external noise, which creates spikes in distance measurements. To address this, a median filter is applied in the code to discard outliers from batches of five measurements and output the median value. Figure 5 shows the median filter implementation.

int medianFilter () {
int readings [5];

// Take 5 raw readings with short gap between each for (int i = 0; i < 5; i ++) {
readings [ i] = sonar . ping_cm () ;
delay (10) ;
}

// Bubble sort readings ascending for (int i = 0; i < 4; i ++) {
for (int j = 0; j < 4 - i ; j ++) {
if ( readings [j ] > readings [j + 1]) { int temp = readings [ j ];
readings [ j] = readings [j + 1]; readings [ j + 1] = temp ;
}
}
}

return readings [2]; // middle value = median }

Figure 5: Code excerpt of median filter implementation using bubble sort

Multiple robots operating in the arena can also cause interference, as ultrasonic bursts from other sensors may trigger false short-distance readings on the echo pin. To reduce the likelihood of this occurring, a time-jitter technique is implemented in the code, which randomises the trigger timing. Figure 6 shows this implementation.

void loop () {

// Read distance via median filter
int distance = medianFilter () ;

if ( distance > 0 && distance < OBSTACLE_THRESHOLD ) { stopMotors () ;
}

// Random delay - breaks s y n c h r o n i s a t i o n with other robots ’ // ultrasonic sensors to prevent crosstalk false positives delay ( random (50 , 150) ) ;
}

Figure 6: Code excerpt of the time jitter technique

### 3.2.3 FC-51 Infrared Sensor Operation

The FC-51 IR sensor detects nearby objects using infrared light reflection. The sensor is positioned between the clamp arms and continuously emits infrared light. When a ball enters the clamp zone, the infrared light reflects back to the sensor, causing it to output a LOW signal. When no ball is present, the sensor outputs HIGH. The Arduino reads this digital signal on a designated pin and triggers clamp closure when a ball is detected. The sensor receives 5V power from the Arduino.

### 3.2.4 Sensor Mounting

The Pixy2 is mounted on the top chassis level with an adjustable angle mount for fine-tuning, allowing it to view both base colours and the clamp mechanism. The HC-SR04 is mounted front-central for forward obstacle detection. The FC-51 IR sensor is integrated into the clamp mechanism for ball detection.

### 3.3 Chassis and Navigation Subsystem

### 3.3.1 Chassis Design

The chassis is 3D-printed using PLA material with 50% infill, which provides strength whilst remaining lightweight [8]. The chassis features a two-level design. The bottom level houses the motors and batteries, whilst the top level holds the Arduino and Pixy2. This arrangement places heavier components low for improved stability. The chassis base measures 146 mm × 145 mm, which fits within the robot’s size constraints. Precision mounting points are integrated into the design to secure all components.

### 3.3.2 Power Supply

A dedicated 9V lithium polymer battery powers the motors via the motor driver. This battery is separate from the Arduino power supply to prevent voltage drops during motor operation. The motors can draw up to 1.1 A each, necessitating a dedicated high-current power source.

### 3.3.3 MKRVRS Motor Driver Operation

The motor driver receives PWM signals from the Arduino to control motor speed and direction. An H-bridge is an electronic circuit that allows voltage to be applied across a load in either direction, enabling motor direction control [9]. The MKRVRS uses an H-bridge circuit with four transistor switches to allow current flow reversal. Figure 7 shows the H-bridge circuit configuration.

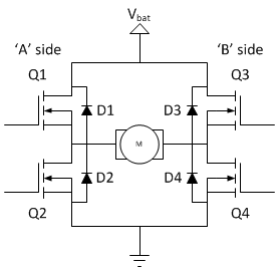
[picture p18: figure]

Figure 7: Diagram of H-bridge circuit

The PWM duty cycle controls the average voltage delivered to the motors. A higher duty cycle produces higher average voltage and results in faster motor rotation. The motor driver independently controls both DC motors, enabling differential steering.

### 3.3.4 DC Motor Operation

The DC motors convert electrical signals from the motor driver into rotational force, which drives the front wheels through attached axles. The motors operate within a 3 to 9 V range, where the applied voltage determines the rotation speed. The motors draw current proportional to the mechanical load they experience.

Differential steering enables directional control [10]. For forward movement, both motors run at the same speed and in the same direction. For turning, the motors run at different speeds in the same direction, where the slower inner wheel and faster outer wheel create an arc. For rotation on the spot, the motors run at the same speed in opposite directions, causing the robot to pivot around the rear caster wheel. The rear ball caster wheel provides a low-friction pivot point, enabling precise positioning.

### 3.3.5 Movement Algorithm

The movement algorithm is outlined in the Subsystem Interaction section.

### 3.4 Ball Handling Subsystem

### 3.4.1 Power Supply

Two servo motors are powered by four AAA lithium polymer batteries connected in series. A separate power source is used to ensure sufficient current for servo operation without affecting the Arduino’s power supply. The motors can draw up to 500 mA each during movement, necessitating dedicated power to avoid overloading the Arduino.

### 3.4.2 Servo Motor Operation

The servo motors control clamp arm position using PWM signals from the Arduino. The PWM pulse width determines the rotation angle. An internal potentiometer measures the shaft position, and the control circuit adjusts the motor until the measured position matches the target position indicated by the pulse width [11]. Both servos receive commands for the same angle to achieve synchronised movement of the clamp arms. The servo response time is 0.3 seconds. When idle or holding position, each servo draws approximately 100 mA, whilst during movement the current draw increases to approximately 500 mA.

### 3.4.3 Clamp Design

The clamp arms are 3D-printed with a curved design to match the ball diameter. The arms rotate inward simultaneously when the servos actuate to create a grip on the ball and secure it during transport.

### 3.4.4 Collection and Release Sequence

During collection, the Pixy2 camera navigates the robot towards the target ball based on colour signature detection. Once nearby, the Pixy2 centres the ball in its frame and aligns it with the open clamp. The Arduino then commands the motors to move forward at low PWM until the ball enters the clamp enclosure. When the FC-51 infrared sensor detects the ball, the Arduino commands the servos to close and secure it. The infrared sensor is mounted between the clamp arms to detect ball entry. The Arduino continuously monitors the sensor state, where HIGH indicates no ball and LOW indicates a ball is present within the detection threshold. During release, the Arduino commands the servos to open the clamp arms, allowing gravity to release the ball into the base.

### 3.5 Subsystem Interaction

See Figure 8 for the autonomous functioning algorithm of the robot.

1: LOG BASE COLOUR & ORIENT

- Pixy2 reads base corner colour plate and detects first signature (signatures 4 through 7) via CCC mode.
- Control stores signature as base target for return.
- Control commands 180° rotation.
- Navigation executes turn so robot now faces arena.
↓

2: SCAN FOR TARGET BALL

- Vision Pixy2 scans for coloured balls via CCC signatures (1 equals red, 2 equals green, 3 equals blue).
- Vision seeks only the current target in sequence (red, green, blue; cycle resets after blue is deposited).
- Vision sends ball position and signature size to Arduino.
- Control compares detected colour to target.
- Control commands rotation if no match is found.

Target Found?

Yes ↓

3: NAVIGATE TOWARD BALL

- Control calculates direction from Pixy2 coordinates and determines motor speeds.
- Control generates PWM (0 to 255) for motor driver.
- Navigation motor driver receives PWM and direction.
- Navigation left and right motors steer differentially while rear caster provides pivot.
- Vision ultrasonic monitors for obstacles and Control adjusts path if detected.
↓

4: FINE POSITION FOR COLLECTION

- Vision Pixy2 monitors ball signature size (increase equals closer).
- Vision sends continuous position updates.
- Control reduces PWM as ball approaches.
- Control fine-tunes alignment to centre ball in clamp path.
- Navigation performs micro-adjustments at reduced speed.
- Navigation stops when ball enters clamp zone.
↓

5: COLLECT BALL

- Vision IR sensor detects ball between clamp arms (sends LOW to Control).
- Control receives IR trigger and commands Pixy2 to verify signature.
- Control closes servos (0° to 90°) if correct signature is confirmed.
- Control opens servos and reverses if wrong signature, then returns to Step 2.
- Ball Handling servos rotate in parallel and clamp arms close together while rubber bands grip ball.
↓

6: VERIFY COLLECTION

- Vision Pixy2 confirms ball signature is still present.
- Vision IR confirms ball remains in clamp.
- Control validates collection and sets ball collected status to TRUE.
- Control increments ball count.
↓

7: SCAN FOR BASE
- Vision Pixy2 performs 360° sweep and scans for stored base signature.
- Vision ensures all signature pixels are fully in frame before the sweep stops.
- Vision sends base position and signature size to Control.
- Control commands continued rotation until base is centred if base is not in view.
↓

8: NAVIGATE TO BASE

- Control calculates path to base and generates motor signals.
- Navigation drives toward base at moderate speed.
- Navigation steers using block X centroid alignment with Pixy2 feedback.
- Vision ultrasonic monitors surroundings and avoids obstacles and other robots.
↓

9: APPROACH BASE (PRECISION)

- Control Phase 1 reduces PWM at 10 to 15 cm, stops then resumes at very low PWM.
- Control Phase 2 crawls forward and stops at less than 5 cm from base.
- Control monitors ultrasonic throughout.
- Vision ultrasonic tracks decreasing distance and sends real-time readings.
- Navigation Phase 1 stops at 10 through 15 cm and resumes at low PWM.
- Navigation Phase 2 performs a full stop at 5 cm.
↓

10: DEPOSIT BALL

- Control detects arrival (ultrasonic threshold met).
- Control sends reverse PWM and commands servo position (90° to 0°).
- Ball Handling servos rotate in reverse and clamp arms open so ball is released and rolls into base.
↓

11: CHECK TASK STATUS

- Control increments deposited ball counter.
- Control checks the order in which the signatures are arranged red, then green, then blue, and repeats the cycle.
- Control evaluates time remaining.
- Control determines if task is complete.

No ↓

Optional: Every 3rd deposit, sweep for stray balls.

← Return to Step 2

Yes ↓
STOP / IDLE
Mission Complete

Figure 8: Flowchart of the ball collection and deposit algorithm

## 4 Risk Management

Within any project, both technical and non-technical risks can negatively impact the ability of a project to achieve its objectives. Risk management is therefore an important practice for identifying potential risks early and creating strategies to mitigate their likelihood and reduce their impact should they occur.

One technical risk involved in developing the robot is damage to components. Several delicate electrical components are used in this project, which can easily be overloaded or physically damaged if handled incorrectly. If components are damaged, it will cost significant time and money, as new components will need to be ordered. This may leave the robot non-functional for testing if components do not arrive in time. To mitigate this risk, datasheets will be consulted to determine the voltage and current limits of components, and all circuit designs will be peer checked to ensure their safety before building. To prevent physical damage, components will be handled carefully at all times and stored in a secure box when not in use. To reduce the impact if this risk still occurs, $15 of the budget has been allocated to purchase replacement components if needed.

Another technical risk is subsystems not working individually or not integrating correctly. If one subsystem fails, the entire robot will become non-functional and fail testing. To minimise this risk, each subsystem will be tested individually to identify any issues, and team meetings will be held frequently to ensure that all subsystems are compatible. Trial runs will also be conducted before testing to identify and troubleshoot any remaining issues.

Battery depletion during testing poses another technical risk. If a battery dies during testing, the robot will become non-functional and fail testing, as manual intervention is not allowed. To mitigate this risk, fresh batteries will be used on testing day, and the weight of the robot will be minimised to reduce power consumption. Trial runs will also be conducted before testing to ensure the batteries have sufficient capacity to last the full duration of testing. Similarly, component failure on testing day is a significant risk. However, due to budget constraints, purchasing spare components for all parts is not possible. Therefore, thorough testing of each component will be conducted throughout the project to ensure reliability.

As mentioned previously, there are also several non-technical risks that must be considered to ensure the project’s success. One non-technical risk is missing both internal and university-set deadlines. Failing to meet a deadline may cause the entire project to fall behind schedule, as tasks are interdependent. This can lead to the project not being completed on time or work being rushed, reducing the robot’s quality. To minimise this risk, a detailed project plan and Gantt chart will be used to track deadlines and task assignments, with regular meetings held every few days to monitor progress. To reduce the impact if this risk still occurs, team members from less intensive or ahead-of-schedule tasks will be reassigned to provide additional support.

Another non-technical risk is the loss of a team member due to unforeseen circumstances such as illness. If a team member with key information or skills becomes unavailable, progress may be impacted. To mitigate this risk, all files will be shared via Microsoft Teams, and at least two group members will maintain a strong understanding of each subsystem, allowing work to continue if this risk occurs.

## 5 Project Plan

### 5.1 Key Points

Planning is essential for completing any project on time and to a high standard. Therefore, a comprehensive project plan has been created to guide the building of the waste sorting robot.

The team has decided to use a Gantt chart as its primary time management tool. This chart shows the project timeline, how tasks depend on each other, what resources are needed, and who is responsible for each task. The work is divided among three subgroups: Mechanical (MG), Electrical (EG), and Programming (PG). The project plan consists of three main phases: Concept Generation and Selection, Initial Design, and Final Design.

The Concept Generation and Selection Phase runs from Monday of Week 2 to Thursday of Week 3. During this phase, the team defines the problem statement, develops design concepts, and selects the best concepts.

The Initial Design Phase runs from Thursday of Week 3 to Monday of Week 7, ending with the Compliance Testing Assessment. This phase focuses on CAD design, circuit layout design, programming, and building the first iteration of the waste sorting robot. Due to time constraints, the Ball Handling Subsystem was designed but not built during this phase.

The Final Design Phase runs from Monday of Week 7 to Thursday of Week 10, the day of the Final Testing Assessment. This phase focuses on improving the first robot iteration based on testing results, adding the Ball Handling Subsystem, and completing the final build.

Throughout the entire process, the budget is strictly managed to ensure the team does not exceed the $50 limit for additional materials beyond the provided kit. So far, only $5 has been spent on a barrel jack connector.

### 5.2 Gantt Chart

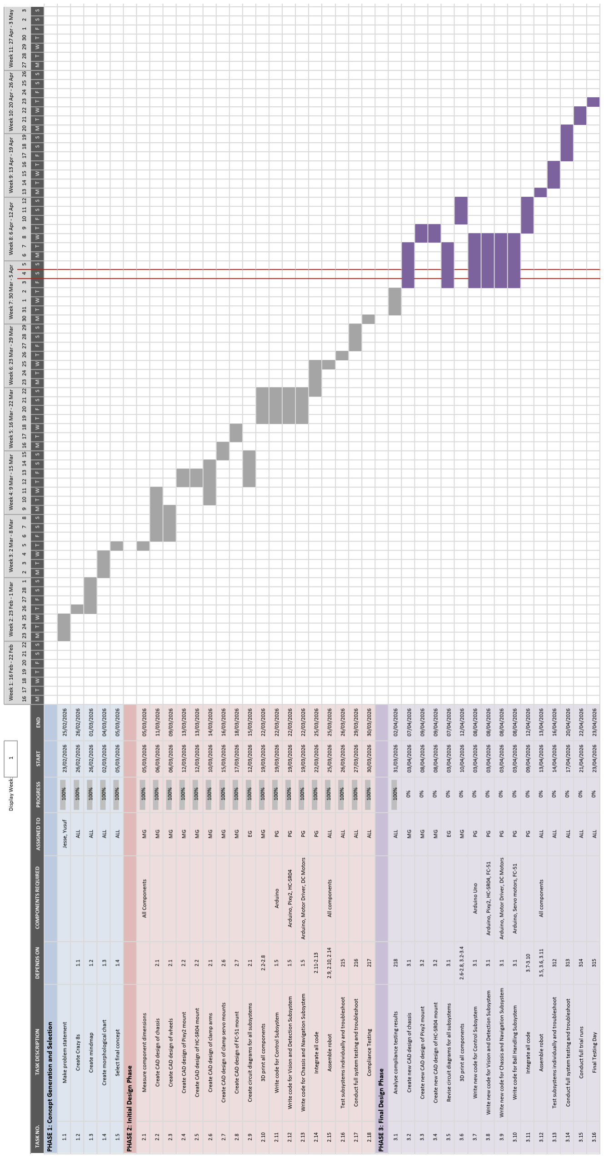
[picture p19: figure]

## 6 Conclusion

Overall, the final robot design satisfies the design objectives, demonstrating the ability to autonomously identify and sort balls that represent plastic waste. This is achieved while adhering to all size, performance, and budget constraints.

The final design is divided into four subsystems: the Control Subsystem, Vision and Detection Subsystem, Chassis and Navigation Subsystem, and Ball Handling Subsystem. This structure allows for easy modification and enables each subsystem to be developed independently.

Throughout the project, the team has improved its ability to collaborate and manage the workload effectively through structured planning and task distribution. The team is satisfied with the final design and will soon begin building the prototype in preparation for final testing.

## 7 References

## References

[1] D. Mesta, “AI and Robotics in Waste Sorting: Enhancing Recycling Efficiency,” Advances in Recycling & Waste Management, vol. 9, no. 4, Aug. 2024, [Online]. Available: https://www.hilarispublisher.com/open-access/ai-and-robotics-in-waste-sorting-enhancing-recyc ling-efficiency-109193.html. (https://www.hilarispublisher.com/open-access/ai-and-robotics-in-waste-sorting-enhancing-recycling-efficiency-109193.html) Accessed: Apr. 5, 2026.
[2] Arduino, Arduino UNO R3 Datasheet, rev. 3 ed., Arduino, Apr. 2024, [Online]. Available: https://docs.arduino.cc/resources/datasheets/A000066-datasheet.pdf. Accessed: Apr. 5, 2026.
[3] ——, “Secrets of Arduino PWM,” [Online], May 2024, available: https://www.arduino.cc/en/Tutorial/SecretsOfArduinoPWM. Accessed: Apr. 5, 2026.
[4] Pixycam, “Color Connected Components,” [Online], Oct. 2018, available: https://docs.pixycam.com/wiki/doku.php?id=wiki:v2:color connected components. Accessed: Apr. 5, 2026.
[5] ——, “CCC API,” [Online], Oct. 2018, available: https://docs.pixycam.com/wiki/doku.php?id=wiki:v2:ccc api. Accessed: Apr. 5, 2026.
[6] Arduino, “SPI,” [Online], Jan. 2026, available: https://docs.arduino.cc/language-reference/en/functions/communication/SPI/. Accessed: Apr. 5, 2026.
[7] A. Prabhu, “How HC-SR04 Ultrasonic Sensor Works & How to Interface It With Arduino,” [Online], Jan. 2026, last Minute Engineers. Available: https://lastminuteengineers.com/arduino-sr04-ultrasonic-sensor-tutorial/. Accessed: Apr. 5, 2026.
[8] S. Farah, D. G. Anderson, and R. Langer, “Physical and mechanical properties of PLA, and their functions in widespread applications—A comprehensive review,” Advanced Drug Delivery Reviews, vol. 107, pp. 367–392, Dec. 2016.

[9] J. Hertz, “H-bridge DC Motor Control Using Complementary PWM, Shoot-through, and Dead-time,” [Online], Aug. 2022, all About Circuits. Available: https://www.allaboutcircuits.com/technical-articles/h-bridge-dc-motor-control-complementary-pulse-width-modulation-pwm-shoot-through-dead-time-pwm/. (https://www.allaboutcircuits.com/technical-articles/h-bridge-dc-motor-control-complementary-pulse-width-modulation-pwm-shoot-through-dead-time-pwm/) Accessed: Apr. 5, 2026.
[10] R. A. Deshmukh and M. A. Hasamnis, “An improvement to the conventional PD scheme for the speed control of a two-wheeled differential steering mobile robot,” International Journal of Information Technology, vol. 15, pp. 3093–3101, Jun. 2023.
[11] D. Aragon-Jurado, A. Morgado-Estevez, and F. P.-P. na, “Low-Cost Servomotor Driver for PFM Control,” Sensors, vol. 18, no. 1, p. 93, Dec. 2017.

## 8 Appendices

### 8.1 Appendix A

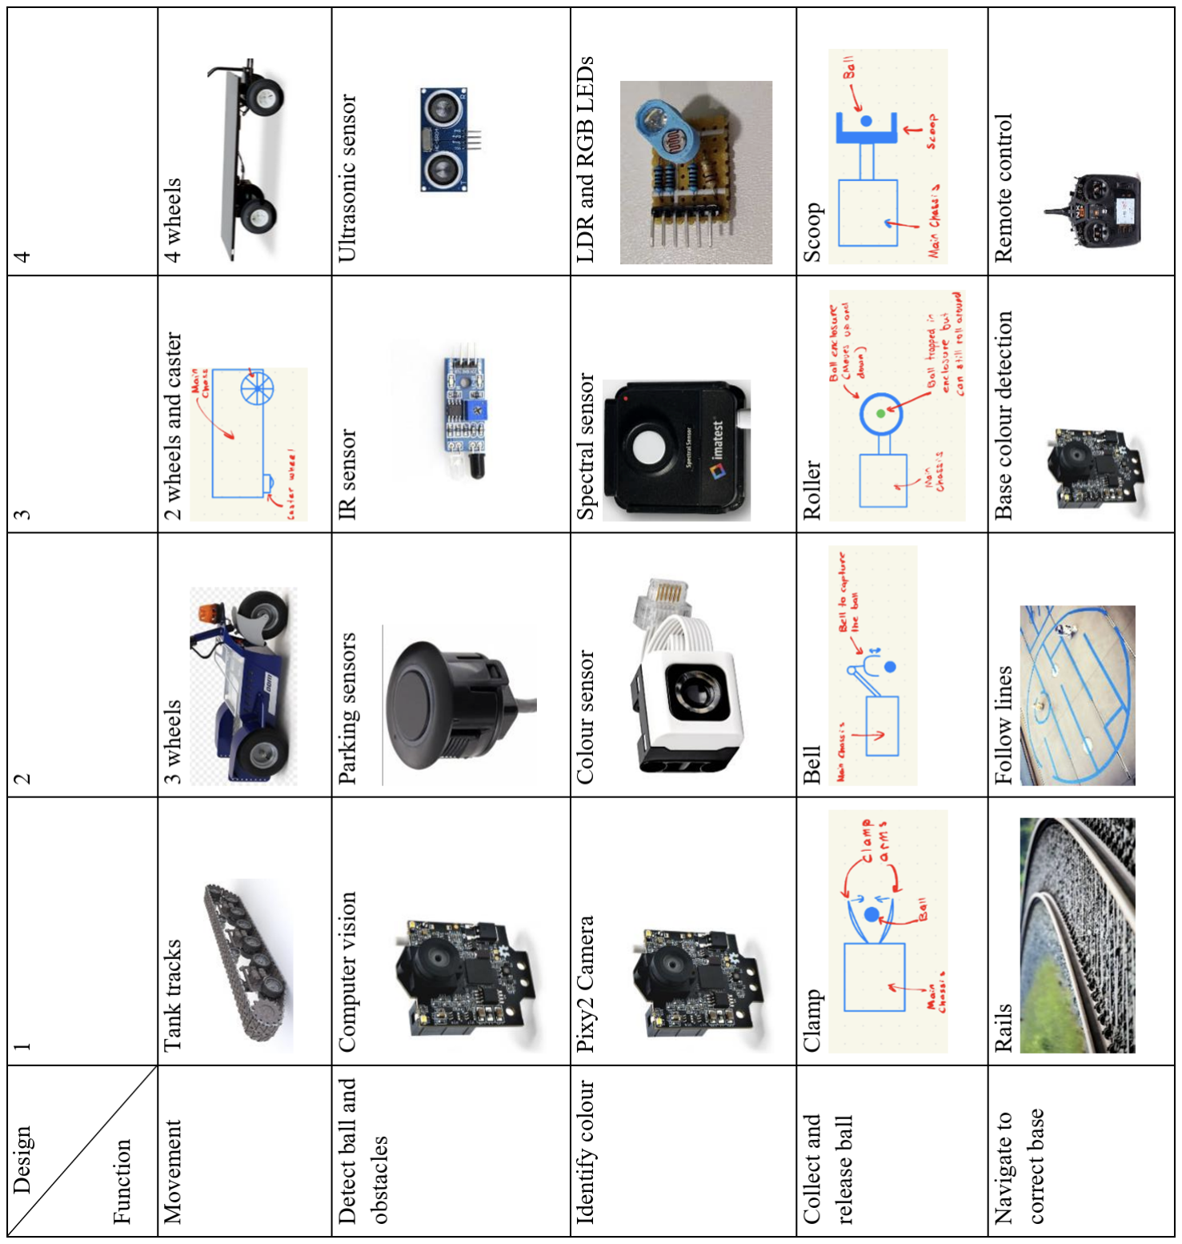
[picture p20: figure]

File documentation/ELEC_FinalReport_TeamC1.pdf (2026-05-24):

# Final Report Cover Sheet

## Project Team Number: C1

Public repository copy. Student numbers and family names have been redacted.

Given Name | Contribution Sections
Jesse | ES, 1.1, 1.2, 1.3, 1.4, 1.5, 1.6, 2.1, 2.2, 2.3, 2.4, 2.5, 3
Trishan | 1.3, 1.4, 1.5, 2.1, 2.2, 2.4, 5
Yusuf | 1.3, 1.4, 1.5, 2.2, 4
Franklin | 1.3, 1.4, 1.5, 2.1, 2.2, 2.4, 2.5
Bradman | 1.1, 1.6, 2.2, 2.3, 2.4, 2.5
Yizhuo | 1.1, 2.1, 2.2

## Executive Summary

Plastic waste on university campuses and in public spaces is often improperly sorted. As the volume of plastic waste generated worldwide increases, manual sorting is becoming less suitable for managing this problem at scale.² Autonomous robots offer a potential solution by providing faster, more accurate, and cheaper plastic waste sorting. Accordingly, this project aims to develop an autonomous prototype robot that sorts plastic waste, represented by coloured balls, into correct categories to explore how automation can improve recycling efficiency and sustainability. The robot will be required to sort red, green, and blue balls, representing HDPE, PET, and PP plastic types respectively, while avoiding yellow balls, which represent non-recyclable material, within a defined arena in an operator-specified order by navigating to the collection zone to collect balls and returning to its base to deposit them. The following report presents the design team’s understanding of the design problem, outlines the robot’s technical specifications, explains its design evolution, and reflects on and evaluates the robot’s performance, with suggestions for future work.

The design for the waste sorting robot is a self-contained WALL-E-inspired system. The robot is based around a dual-level PLA chassis with an outer shell and moves using two front wheels and a rear caster wheel. It is controlled by an Arduino Uno microcontroller and powered by two 9 V alkaline batteries and four AAA batteries. The robot also features several sensors to detect balls and obstacles. To collect balls, it uses a curved, servo-actuated clamp that closes around each ball.

During development, the design team focused on keeping the design simple, reliable, and easy to modify. As such, notable design features include an LCD for simple and clear user feedback, a durable collisionresistant PLA chassis, and a subsystem breakdown that allows each part of the robot to be developed simultaneously and easily adjusted. However, the final design of the robot is limited as it is specialised for ball collection in a controlled arena and would require significant modification for real-world plastic waste sorting.

Overall, the design successfully met the project’s performance objectives in a cost-effective manner by accurately detecting and sorting different coloured balls. The project also provided valuable insight into the effectiveness and potential of autonomous waste-sorting robots.

ii

## Contents

1 Final Design Implementation | 1
1.1 Problem and Objectives | | 1
1.2 Concept Overview | | 1
1.3 Detailed Design | | 2
1.3.1 | Mechanical Design | | 2
1.3.2 | Electrical Design | | 4
1.3.3 | Software Design | | 5
1.4 Subsystems and Integration | | 5
1.4.1 | Control Subsystem | | 5
1.4.2 | Vision and Detection Subsystem | | 6
1.4.3 | Chassis and Navigation Subsystem | | 6
1.4.4 | Ball Handling Subsystem | | 6
1.4.5 | Subsystem Integration | | 7
1.5 Design Evolution, Testing Influence, and Technical Justification | | 8
1.5.1 | Mechanical Design Changes | | 8
1.5.2 | Electrical Design Changes | | 8
1.5.3 | Software Design Changes | | 9
1.6 Cost Estimate | | 9
2 Final Design Evaluation | 10
2.1 Design Performance and Testing Results | 10
2.2 Challenges and Limitations | 11
2.3 Cost-Benefit Analysis | 12
2.4 Improvements and Future Work | 13
2.5 Lessons Learned | 13
3 Conclusion | 13
4 References | 14
5 Appendices | 15
5.1 Source Code Links | 15

## List of Figures

1 | 3D render of final waste sorting robot design | | 1
2 | Technical drawings of the bottom level of the robot chassis | | 2
3 | Technical drawings of the top level of the robot chassis | | 2
4 | Technical drawing of the robot chassis without outer shell, isometric view | | 3
5 | Technical drawings of the front two 3D printed wheels | | 3
6 | Technical drawing of the ball collection clamp mechanism, isometric view | | 4
7 | Circuit Diagram of the robot, without perfboard and SPDT switch | | 5
8 | Flowchart of the ball collection and deposit algorithm | | 7
9 | Technical drawings of the battery mount and PixyCam and HC-SR04 mount, isometric
view | | 8
10 | Diagram of the ball searching algorithm fault in Final Testing | 11

## List of Tables

1 | Cost estimate | 10
2 | Cost-benefit analysis | 12

iii

## 1 Final Design Implementation

### 1.1 Problem and Objectives

Plastic waste on university campuses and in public spaces is often improperly sorted, leading to contamination of recycling streams and reduced effectiveness. Indeed, a 2024 Cleanaway report found that 40% of Australians do not separate soft plastics from hard plastics before recycling.¹ As the volume of plastic waste generated worldwide increases, manual sorting, which is labour-intensive and prone to error, is becoming less suitable for managing this problem at scale. This project aims to address this issue by developing an autonomous prototype waste sorting robot to explore how automation can improve recycling efficiency and sustainability. The robot must operate within a defined arena and sort red, green, and blue balls, representing HDPE, PET, and PP plastic types respectively, while avoiding yellow balls, which represent non-recyclable material. It must also collect and sort the balls in an operator-specified order. There were a number of restrictions on the design. These are: the robot must be self-contained, with maximum dimensions of 200 mm x 200 mm x 200 mm; the robot must use no more than 50 AUD in additional materials beyond the provided kit; the project must be completed and ready for testing by 23 April 2026.

### 1.2 Concept Overview

The final design is an autonomous, WALL-E-inspired waste sorting robot. At the start of operation, the robot logs its base colour. It then turns and navigates to the central collection zone using two front drive wheels and a rear caster wheel. Once there, it uses a PixyCam 2.1 and other sensors to locate the target coloured ball while avoiding obstacles. It then collects the target ball using a front-mounted clamp mechanism and returns to its logged base colour, where the ball is deposited. The overall design of the robot is shown in Figure 1.


Figure 1: 3D render of final waste sorting robot design

During development, the design approach focused on keeping the design of the robot simple, reliable, and easy to modify. As such, the robot was divided into four distinct subsystems. This modular breakdown helps simplify system integration and allows different parts of the robot to be modified without redesigning the overall system. The four subsystems are: the Control Subsystem, the Vision and Detection Subsystem, the Chassis and Navigation Subsystem, and the Ball Handling Subsystem. Further detail about each subsystem and their interactions is explained in Section 1.4, Subsystems and Integration.

### 1.3 Detailed Design

### 1.3.1 Mechanical Design

The chassis is 3D-printed from PLA and split into two levels, each using screw holes, cutouts, and locating pins to mount the components. The bottom level is 146.5 mm x 145 mm and contains the following components: two 9 V alkaline batteries, four AAA batteries, two N20 geared DC motors, the MKRVRS motor driver, two FS90MG servo motors with 3D-printed clamp arms, two front wheels with rubber tyres, a rear caster wheel, a PixyCam 2.1, an HC-SR04 ultrasonic sensor, and a TCRT5000 infrared sensor. The layout of the bottom level can be seen in Figure 2.

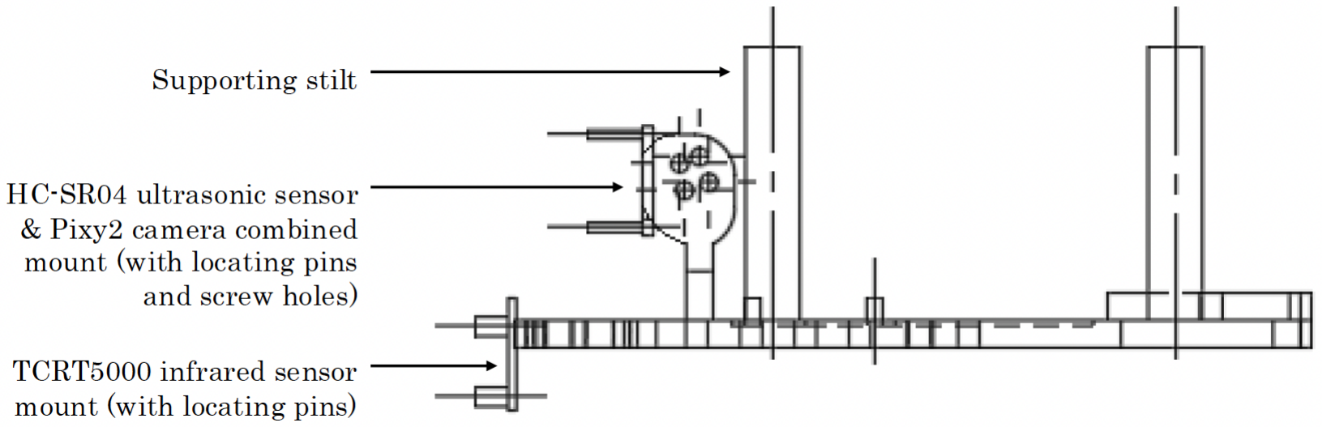
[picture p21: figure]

(a) Top view of the chassis’ bottom level | (b) Side view of the chassis’ bottom level.

Figure 2: Technical drawings of the bottom level of the robot chassis

The top level is 98 mm x 133 mm and contains the robot’s logic: an Arduino Uno, an Arduino shield, a perfboard, and an LCD display. The layout of the top level is shown in Figure 3.

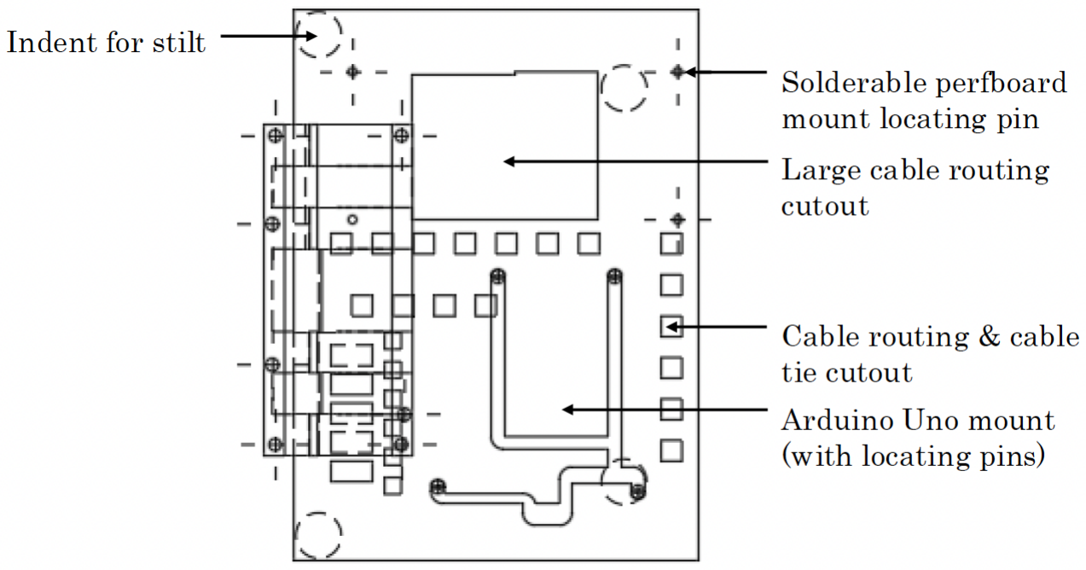
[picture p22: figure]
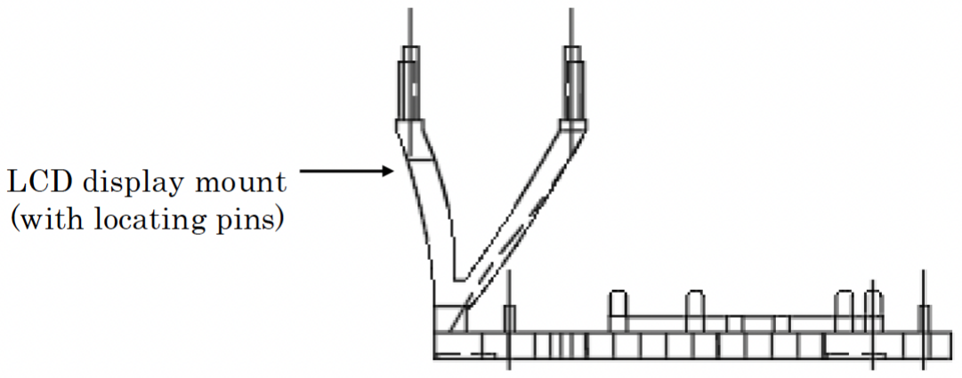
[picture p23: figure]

(a) Top view of the chassis’ top level | (b) Side view of the chassis’ top level

Figure 3: Technical drawings of the top level of the robot chassis

The overall layout of the chassis is shown in Figure 4.


Figure 4: Technical drawing of the robot chassis without outer shell, isometric view

Cable management is handled through small cutouts on both levels which are used to route wires and anchor cable ties, keeping the wiring clean and easy to trace. A larger cutout also sits directly beneath the perfboard, linking the two levels. The PixyCam and HC-SR04 ultrasonic sensor mount is integrated into the baseplate, as shown in Figure 9a. The HC-SR04 slots into a small plate using locating pins that align with its screw holes, with space left behind for cable clearance. The PixyCam attaches to a separate small plate using its own screw holes. This plate is then bolted to the upper part of the mount using one of two hole positions, setting the camera at either a 10° or 20° downward angle.

The drive system uses two front wheels powered by N20 motors and a rear caster wheel, allowing the robot to turn on the spot. The front wheels were designed in-house with a Y-spoke pattern, shown in Figure 5.


(a) Side view of the front wheels. | (b) Front view of the front wheels.

Figure 5: Technical drawings of the front two 3D printed wheels

The overall layout of the chassis is shown in Figure 4. The clamping mechanism is positioned at the front of the robot and is intentionally simple. Two servos sit in cutouts on the baseplate, each connected to a clamp arm. The servos rotate in opposite directions to close around the ball. Between the servos, the TCRT5000 IR sensor is mounted on two small locating pins that pass through its screw holes. The clamp mechanism is shown in Figure 6.


Figure 6: Technical drawing of the ball collection clamp mechanism, isometric view

Sitting over the dual-level base is a removable PLA shell that attaches using locating pin holes around the edge of the bottom plate, allowing it to be easily removed and reattached. The shell includes cutouts for the LCD display, PixyCam, HC-SR04, and TCRT5000, and is finished with rust-coloured spray paint and a WALL-E head mounted on top to match the robot’s intended aesthetic.

### 1.3.2 Electrical Design

The Arduino Uno microcontroller functions as the main control unit for the robot.³ A shield is fitted over the Arduino to provide reliable electrical connections. As described in Section 1.3.1, Mechanical Design, the Arduino is mounted on the top level of the chassis. A solderable perfboard serves as the main connection pathway between the two levels, distributing 5 V and GND through power rails formed on each level. Any additional cables are routed through cutouts in the baseplate.

The circuit is powered by two 9 V alkaline batteries and four 1.5 V AAA alkaline batteries. The first 9 V battery powers the Arduino via the power jack, with a clip and switch soldered to the power jack for connection. The second 9 V battery supplies the MKRVRS motor driver, while the four AAA batteries power the two FS90MG servo motors. The motor driver’s regulated 5 V output is also connected to the shared 5 V and GND rails³
to provide additional current to other components if needed. A power switch is also included in the circuit to allow the robot to be easily turned off and on.

To smooth power fluctuations, two 1000 µF capacitors are used. One capacitor is placed across the main power rails, and the other is placed across the terminals of the 9 V battery supplying the Arduino. All components share a common ground with the Arduino to provide a 0 V reference, ensuring signals can be transmitted reliably across the system.³

The remaining component connections are shown in Figure 7. The perfboard and power switch are not included in Figure 7 to maintain clarity.

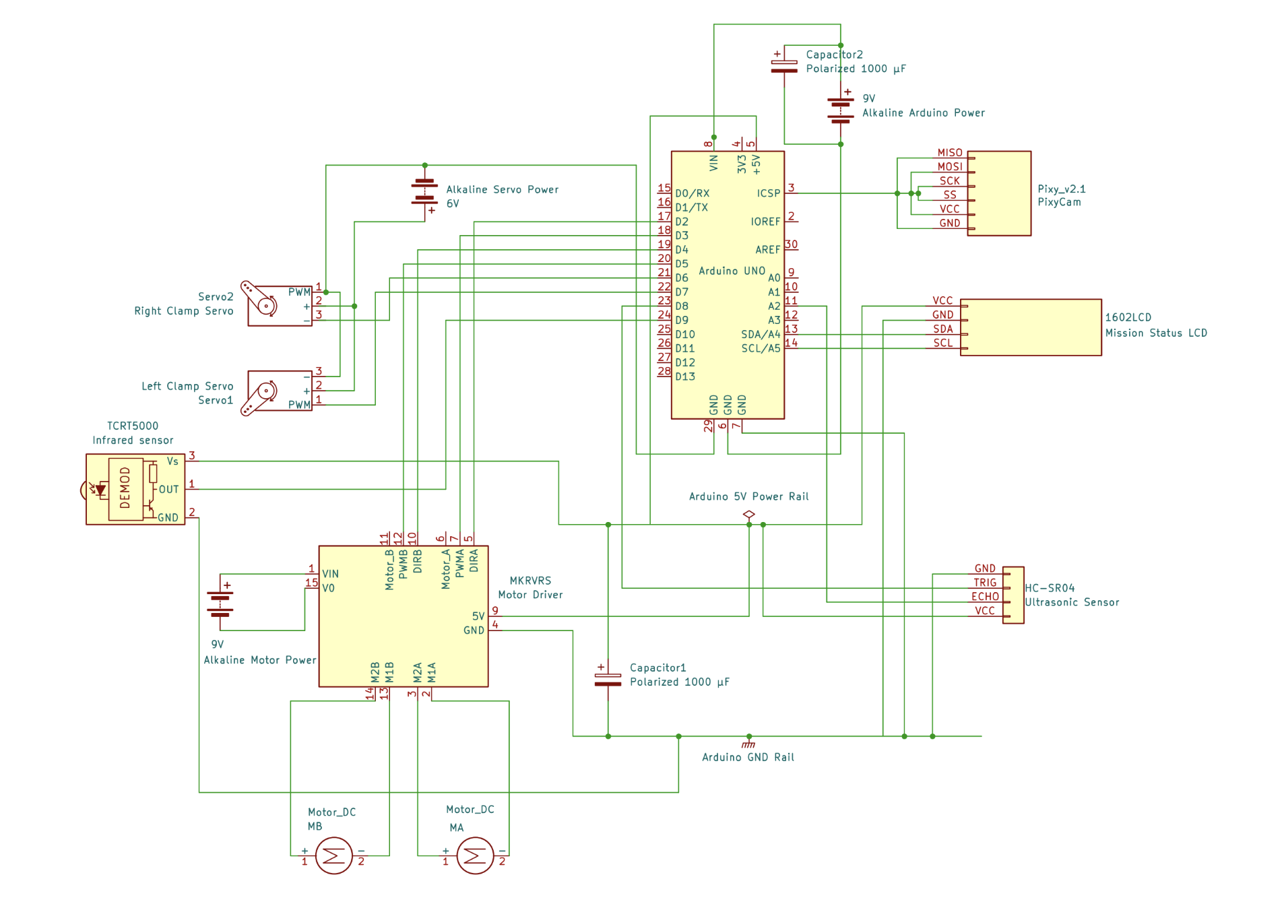
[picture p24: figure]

Figure 7: Circuit Diagram of the robot, without perfboard and SPDT switch.

### 1.3.3 Software Design

The software is implemented on the Arduino Uno using a modular structure with clear task separation.³ The setup() routine initializes sensors and actuators, logs the base signature at startup, and establishes a known mechanical state. The loop() routine then executes repeated colour cycles in the required order. Each cycle calls dedicated functions for search, centring, chase, clamp actuation, return-to-base, and deposit, so motion control and decision logic remain consistent across all three target colours. Operational reliability is ensured through rule-based checks and feedback at each stage. PixyCam 2.1 block position and size are used for steering and approach control, the IR sensor confirms capture before transition to return mode, and ultrasonic readings support obstacle handling during normal navigation.⁵, 7, 10 Timeout limits, confirmation checks, and orientation state tracking are also applied to reduce false transitions and prevent repeated turning errors, which helps the robot recover from temporary loss of visual targets and continue the mission sequence. See Section 1.4.5, Subsystem Integration for more details.

### 1.4 Subsystems and Integration

### 1.4.1 Control Subsystem

The Control Subsystem manages the overall operation of the robot.³
| It consists of an Arduino Uno
microcontroller and an LCD display, which provides simple user feedback.

The subsystem operates by the Arduino receiving sensor data from the Vision and Detection Subsystem. Specifically, the PixyCam 2.1 detects coloured balls and the robot’s base, the HC-SR04 ultrasonic sensor detects obstacles, and the TCRT5000 infrared sensor detects when a ball is in the clamp. The Arduino processes this data using conditional logic in the code to determine the commands sent to the Chassis and Navigation Subsystem or the Ball Handling Subsystem. This loop continuously repeats by reading sensor inputs, evaluating conditions, and sending commands. These commands are sent using PWM signals.⁶ For the MKRVRS motor driver, the PWM duty cycle controls motor speed, thereby controlling the movement of the robot.⁶ For the FS90MG servo motors, the PWM pulse width controls the rotation angle, thereby opening and closing the clamp.¹²

### 1.4.2 Vision and Detection Subsystem

The Vision and Detection Subsystem is responsible for gathering information about the robot’s surroundings and sending this sensor data to the Control Subsystem. It consists of a PixyCam 2.1, a HC-SR04 ultrasonic sensor, and a TCRT5000 infrared sensor.

The PixyCam uses trained colour signatures in Colour Connected Components mode to detect red, green, and blue balls, as well as base locations.⁴, 5 Signatures 1 to 3 identify red, green, and blue balls respectively, while signatures 4 to 7 identify the four corner bases. At startup, the robot logs its base signature and the corresponding signature size in pixels, enabling accurate return navigation and ball deposit. The HC-SR04 supports navigation by measuring distance to obstacles using 40 kHz ultrasonic pulses.⁷⁻⁹ To address noise-induced spikes in distance readings, a median filter is applied in the code to batches of five measurements to remove outliers and output the median value.⁸
In addition, a time-jitter method randomises trigger timing, reducing the likelihood of interference from other ultrasonic sensors operating in the arena. The TCRT5000 uses infrared light to detect balls within the clamp.¹⁰, 11 When a ball enters the clamp area, reflected infrared light causes the sensor to output a LOW signal, which the Arduino reads and uses to send a command to close the clamp.¹⁰, 11 When no ball is present, it outputs HIGH.

### 1.4.3 Chassis and Navigation Subsystem

The Chassis and Navigation Subsystem is responsible for providing physical housing for all components and moving the robot throughout the arena. It consists of a PLA chassis, an MKRVRS motor driver, two N20 geared DC motors, two front wheels with rubber tyres, and one rear ball caster wheel. The structure and layout of the chassis are explained in Section 1.3.1, Mechanical Design.

The subsystem operates by the MKRVRS motor driver receiving movement commands from the Arduino Uno in the Control Subsystem in the form of PWM signals. The PWM duty cycle controls the average voltage applied to the DC motors, thereby controlling wheel speed through the attached axles. The motor driver independently controls both DC motors, enabling differential steering. For forward movement, both DC motors run at the same speed and in the same direction. For turning on the spot, the DC motors run at the same speed in opposite directions, causing the robot to pivot around the rear caster wheel. The movement algorithm is explained in Section 1.4.5, Subsystem Integration.

### 1.4.4 Ball Handling Subsystem

The Ball Handling Subsystem is responsible for collecting and releasing the coloured balls during operation. It consists of two FS90MG servo motors and two 3D-printed clamp arms.¹²

The subsystem operates by the FS90MG servos receiving actuation commands from the Arduino Uno in the Control Subsystem in the form of PWM signals.³, 12 The PWM pulse width controls servo rotation, thereby opening and closing the clamp arms, which are attached directly to the servos. As explained further in Section 1.4.5, Subsystem Integration, the Arduino sends actuation commands when the TCRT5000 infrared sensor mounted in the clamp detects a ball and sends a LOW signal to the Arduino.

### 1.4.5 Subsystem Integration

1: LOG BASE + ORIENT

- Vision and Detection Subsystem: PixyCam 2.1 reads the base colour signature (4 to 7) and block size at startup.
- Control Subsystem: stores this base reference and sets the initial mission state.
- Chassis and Navigation Subsystem: drive motors execute a brief reverse and turn so the chassis faces the arena.

↓

2: SELECT TARGET + SCAN

- Control Subsystem: selects the target in sequence RED (1), GREEN (2), then BLUE (3).
- Vision and Detection Subsystem + Chassis and Navigation Subsystem: PixyCam 2.1 scans while motors perform a 180° sweep.
- Control Subsystem + Chassis and Navigation Subsystem: if no valid target is found, a timed forward push is commanded and scanning repeats.

Target Found?

Yes ↓

3: NAVIGATE TOWARD BALL

- Vision and Detection Subsystem: PixyCam 2.1 provides target centroid and area continuously.
- Control Subsystem: computes differential PWM from x-error and proximity.
- Chassis and Navigation Subsystem: MKRVRS drives left and right motors for differential steering and controlled approach speed.

↓

4: OBSTACLE HANDLING

- Vision and Detection Subsystem: ultrasonic distance is medianfiltered during normal navigation.
- Control Subsystem: if distance is ≤10 cm, it waits up to 3 s and reevaluates clearance.
- Chassis and Navigation Subsystem: if still blocked, motors reverse slightly, rescan, and re-enter mission flow.

↓

5: COLLECT BALL

- Vision and Detection Subsystem: clamp IR sensor detects ball presence (active LOW).
- Control Subsystem (Software): validates capture state and issues the clamp-close command.
- Ball Handling Subsystem: both servos close clamp arms to secure the ball; if capture is lost, the Control Subsystem returns to search and chase.

↓

6: SCAN FOR HOME BASE

- Vision and Detection Subsystem: PixyCam 2.1 searches for the stored base signature.
- Control Subsystem: commands a 360° sweep until base is reacquired and confirmed.
- Chassis and Navigation Subsystem: motors rotate and then centre the base in frame before approach.

↓

7: RETURN TO BASE

- Vision and Detection Subsystem: PixyCam 2.1 provides base centroid and apparent size updates.
- Control Subsystem: steers to centreline and checks base-size threshold for arrival.
- Chassis and Navigation Subsystem: motor commands bring the chassis to deposit position; obstacle logic is suppressed in this phase.

↓

8: DEPOSIT SEQUENCE

- Control Subsystem (Software): runs a timed deposit routine after base-arrival confirmation.
- Chassis and Navigation Subsystem + Ball Handling Subsystem: motors inch forward, then servos open the clamp to release the ball.
- Ball Handling Subsystem + Chassis and Navigation Subsystem: ball is released into the base zone, then the chassis backs up for clearance.

↓

9: REORIENT + CONTINUE

- Control Subsystem: updates mission state and advances colour index (R→G→B→repeat).
- Chassis and Navigation Subsystem: motors execute a 180° reorientation toward the arena.
- All subsystems: sensing, decision, and actuation loop restarts for the next target cycle.

Not complete ↓
← Return to Step 2

Complete ↓
STOP / IDLE

Figure 8: Flowchart of the ball collection and deposit algorithm

### 1.5 Design Evolution, Testing Influence, and Technical Justification

### 1.5.1 Mechanical Design Changes

During the development of the final waste sorting robot design, changes were first made to the proposed mechanical design. The initial focus was on adding dedicated component mounts to the chassis. A recessed mount for the rear caster wheel was first added to the bottom plate, as the original configuration made the chassis uneven and caused several components to shift during operation. A dedicated battery mount was then introduced on the bottom plate. This was required as compliance testing showed that the two 9 V batteries were moving during operation. This movement shifted the centre of mass of the robot and resulted in inconsistent steering. The battery mount is shown in Figure 9b.


(a) Technical drawing of the PixyCam and HC-SR04 mount, isometric


(b) Technical drawing of the 9 V battery mount, isometric

Figure 9: Technical drawings of the battery mount and PixyCam and HC-SR04 mount, isometric view.

On the top level, a mount for the LCD display was added. This improved visibility and prevented movement of the display during operation. Following this, a combined mount for the PixyCam 2.1 and HC-SR04 ultrasonic sensor was implemented. This allowed the PixyCam to be positioned at either a 10° or 20° downward angle, improving the detection of nearby balls. It also reduced ambient light interference observed during testing, which affected camera exposure and reduced colour detection accuracy. Furthermore, mounting the ultrasonic sensor on the same bracket saved space and ensured obstacle detection remained aligned with the robot’s forward direction. The combined PixyCam and HC-SR04 ultrasonic sensor mount is shown in Figure 9a.

Once these mounting changes were complete, cutouts were introduced in both plates to allow wires to pass cleanly between levels. With the chassis layout established, the front motor mounts were repositioned outward and the width of the front wheels was reduced from 25 mm to 15 mm. This was necessary, as compliance testing showed the wheels were scraping against the chassis during operation. Finally, rubber tyres were added to the wheels due to the inconsistent grip provided by the bare PLA material. The higher coefficient of friction of the rubber improved traction and increased turning accuracy.

### 1.5.2 Electrical Design Changes

Changes to the proposed electrical design were implemented following modifications to the mechanical design. The solderless breadboard was first replaced with a solderable perfboard. This was necessary, as loose jumper connections may cause intermittent faults during operation. Soldered joints provide fixed and more reliable electrical connections.

After this, the MKRVRS motor driver’s regulated 5 V output was connected to the shared main power rails. This was necessary because, during testing, the LCD display was dim under load. Connecting the regulated 5 V output ensured the LCD display and PixyCam 2.1 received sufficient current, resolving the dimming issue.

Two 1000 µF capacitors were added next, one across the main power rails and one across the Arduino’s 9 V supply. This was required after components were observed to intermittently turn on and off. This was caused by short voltage dips due to sudden current draw from the N20 geared DC motors and FS90MG servo motors. The capacitors help smooth the power supply by storing charge and releasing it during short voltage dips.¹⁵ A power switch was also added to allow the robot to be powered on and off easily.

Finally, several Arduino Uno pins were reassigned. This was required because, during testing, the HC-SR04 ultrasonic sensor and PixyCam were not working together effectively for navigation. The PixyCam ICSP connector uses the SPI bus, which conflicts with Arduino digital pins 10–13.³, 5 As such, TRIG was moved from D9 to D8, ECHO from D10 to A2, and the TCRT5000 infrared sensor signal from D11 to D9 (relative to the Design Proposal pin layout). Reassigning these signals freed the SPI lines and allowed both sensors to operate together.

### 1.5.3 Software Design Changes

From prefinal code v2.ino to finaltesting.ino (see Appendix), the main software change was a shift from simple sequential actions to a more robust state-driven mission flow. The final logic introduced clearer phase control for search, chase, return, and deposit, including orientation state tracking to prevent repeated turns between cycles. Detection handling was also tightened by adding signature confirmation during sweeps and stronger reacquisition behavior when a target was briefly lost, reducing false locks and improving continuity during competition runs.

Obstacle and deposit logic were also revised to improve reliability under real arena conditions. In earlier code, avoidance behavior relied on faster one-step reactions and ultrasonic-based deposit thresholds that were less consistent in practice. The final version uses a staged obstacle routine with timed clearance checks, controlled reverse and rescan behavior, and a calibrated timed deposit sequence with explicit pullback and reorientation. These changes improved repeatability of ball collection cycles, reduced deadlock scenarios near obstacles, and produced more consistent return-to-search transitions after each deposit.

Relative to the Design Proposal flowchart, the final implemented algorithm also simplified and reordered several stages. The proposal separated collection into distinct ”collect” and ”verify” phases and used a two-phase ultrasonic precision approach for base deposition, whereas the final logic confirms capture directly through IR-triggered clamp closure during chase and performs a fixed-time deposit approach after visual base reacquisition. The final version also added stronger recovery behavior, including periodic 180° sweeps, 360° reacquisition, and orientation state handling between cycles, which produced a more stable mission loop under competition conditions than the original proposal sequence.

### 1.6 Cost Estimate

The waste sorting robot was constructed primarily from components supplied in the kit, supplemented by additional materials sourced externally.³, 4, 7, 10, 12, 13 Table 1 presents the cost estimate for the robot.

Component | Qty | Supplier | Retail Price (AUD) Logged Price (AUD)
Arduino Uno | 1 | Kit | 50.00 | 0.00
Arduino prototyping shield | 1 | Kit | 14.95 | 0.00
PixyCam 2.1 | 1 | Kit | 110.00 | 0.00
HC-SR04 ultrasonic sensor | 1 | Kit | 1.95 | 0.00
TCRT5000 infrared sensor | 1 | Kit | 3.50 | 0.00
N20 DC motor | 2 | Kit | 28.30 | 0.00
FS90MG servo motor | 2 | Kit | 14.80 | 0.00
MKR VRS motor driver | 1 | Kit | 6.00 | 0.00
Rubber tyre | 2 | Pre-owned | 6.10 | 6.10
Caster wheel | 1 | Kit | 4.15 | 0.00
Energizer 9 V alkaline battery | 2 | Woolworths | 12.50 | 12.50
Energizer AAA alkaline battery | 4 | Woolworths | 8.00 | 8.00
9 V battery connector | 2 | Kit / Jaycar | 3.20 | 1.60
4×AAA battery case | 1 | Kit | 3.80 | 0.00
SPDT miniature toggle switch | 1 | Jaycar | 2.95 | 2.95
16×2 I²C LCD display | 1 | Amazon | 12.95 | 12.95
Solderable perfboard | 1 | Kit | 3.10 | 0.00
1000 µF capacitor | 2 | Makerspace | 3.90 | 0.00
Dulux rust paint | ≈50 g | Bunnings | 2.00 | 2.00
Total | | | 292.15 | 46.10

Table 1: Cost estimate

Components supplied in the kit were not counted towards the logged price and therefore did not contribute to the 50 AUD budget. The rubber tyres were pre-owned, so their cost was estimated using a listing for a similar tyre on Amazon. The cost of the paint was estimated by taking the proportional cost based on the quantity used by the design team.

## 2 Final Design Evaluation

### 2.1 Design Performance and Testing Results

The final waste sorting robot successfully met all of the project’s objectives while abiding by all design restrictions. During the 10-minute time trial on 23 April 2026, the robot collected 16 balls in the operator-specified red, green, and blue order while correctly avoiding the yellow balls. As a result, the design team placed second in the waste sorting competition. This was achieved while remaining within the 200 mm x 200 mm x 200 mm size constraint and the 50 AUD additional materials budget. The robot performed as expected throughout final testing, owing to the several practice runs the team conducted beforehand.

Several aspects of the robot performed well during testing. The ball alignment algorithm consistently aligned the target ball with the clamp mechanism, allowing for accurate collection. It was also particularly effective in recovery scenarios; when the target ball was knocked away by one of the other two robots in the arena, the robot would reverse and recentre on it. Ball colour recognition was similarly reliable, allowing the robot to locate target balls quickly while avoiding the yellow balls. The obstacle detection algorithm also proved integral to the robot’s success. When an obstacle was detected, the robot would wait three seconds, reverse, and perform a 360° sweep to search for nearby balls. If none were detected, it would rotate 180°, move forward, and carry out further sweeps to resume searching. This behaviour allowed the robot to avoid collisions with the arena walls and other robots while quickly returning to ball collection.

The ball searching algorithm, however, did not perform as intended. As explained in Section 1.4.5, Subsystem Integration, when no target ball is detected, the robot is designed to move forward, perform a 180° sweep, and resume forward movement, repeating the process until a target ball is found. During testing, the robot frequently moved forward several times without performing a sweep, causing it to drive across the arena toward the opposite wall without detecting the target ball, as shown in Figure 10. Nevertheless, the impact of this fault was minimised as the obstacle detection algorithm would reroute the robot back toward the ball collection zone before it reached the wall.

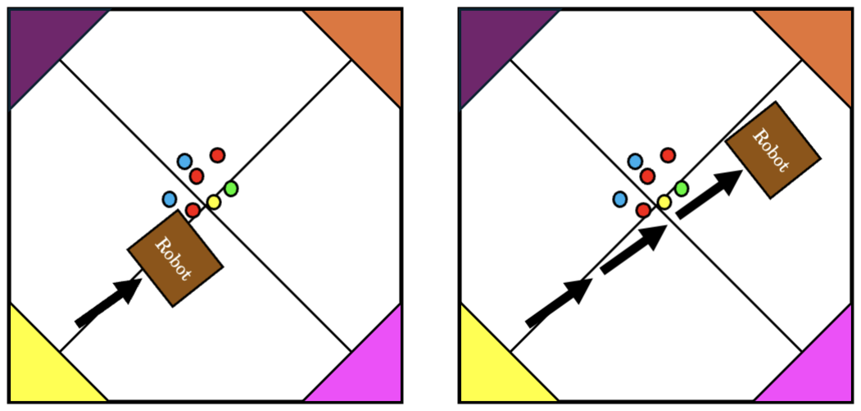
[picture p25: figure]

Figure 10: Diagram of the ball searching algorithm fault in Final Testing.

### 2.2 Challenges and Limitations

During the robot’s development, the design team faced several time-related, resource, and technical challenges. The most significant challenge was the short three-and-a-half-week gap between Compliance Testing and Final Testing. This short gap forced the team to work intensively in the lead-up to allow time for trial runs and troubleshooting. This issue was worsened by a delay in shipping the LCD display, which took over a week to arrive. Because the LCD display needed to be physically measured to design its mount and soldered to the circuit, its late arrival slowed progress on the entire robot. As a result of these time-related challenges, the robot’s operational algorithm was not fully refined by Final Testing, limiting its overall performance.

Another challenge faced by the design team was managing the 50 AUD budget for additional components beyond the provided kit. This constraint required the team to identify cost-effective solutions to issues that could otherwise be resolved with more expensive components. For example, the severity of the power fluctuation issues, addressed using two 1000 µF capacitors, may have been reduced if the budget had allowed for alkaline batteries to be replaced with lithium-polymer batteries. These batteries provide a more stable voltage under load, particularly when components such as N20 DC motors or FS90MG servo motors draw high currents. Nevertheless, the budget constraints did not significantly impact the robot’s performance or its testing results.

The design team also faced various technical challenges while developing the robot. The most notable was managing the 200 mm × 200 mm × 200 mm size restriction. This constraint required the team to carefully plan the placement of components, mounts, and wiring cut-outs across both chassis levels to ensure all components fit within the robot without compromising functionality or accessibility for troubleshooting. Subsystem integration also proved difficult. The circuit layout and software had to be repeatedly tested and refined to ensure each subsystem functioned as intended. This process was time-consuming, as some issues spanned multiple subsystems. As a result, individual components often had to be isolated to identify and resolve faults. Despite this, these technical challenges did not limit the robot’s performance or testing outcomes.

### 2.3 Cost-Benefit Analysis

A simple cost-benefit analysis was carried out on the main components of the robot to determine whether the final design is cost-effective relative to its performance. Each component was rated on a scale of 1 to 5, where 5 is excellent value, 4 good, 3 acceptable, 2 poor, and 1 unjustified. Components supplied in the kit were evaluated using their retail price, as this reflects the true cost of replicating the design. The results are presented in Table 2. Overall, the average rating across the components was 4.29, indicating that the final design is highly cost-effective relative to its performance.

Component | Retail Price (AUD) Justification | Rating
Arduino Uno | 50.00 | This component was important as it served as the main control unit of the robot.
The price is reasonable given its reliability and broad compatibility.

4

PixyCam 2.1 | 110.00 | This component was critical as it handled all colour detection and target tracking.
The high price is justified by its central role in the robot’s performance.

4

HC-SR04 ultrasonic
sensor

1.95 This component was important as it enabled obstacle detection during navigation. The price is very low for the functionality provided.

5

TCRT5000 infrared
sensor

3.50 This component was important as it detected when a ball was inside the clamp. The price is very low for a reliable and simple sensor.

5

N20 DC motor | 28.30 | This component was important as it drove the front wheels of the robot. The price
is moderate but reasonable for the torque and speed delivered.

4

FS90MG servo motor | 14.80 | This component was important as it actuated the clamp arms. The price is fair given
its durability and reliable performance.

4

MKR VRS motor driver | 6.00 | This component was important as it controlled the DC motors, allowing the robot
to move forward, backward, and turn. The price is low for its functionality.

5

Rubber tyre | 6.10 | This component was important as it improved wheel traction and turning accuracy.
The price is low for a noticeable performance gain.

5

Caster wheel | 4.15 | This component was important as it provided rear support and allowed the robot to
pivot on the spot. The price is very low for its role.

5

Energizer 9 V & AAA
alkaline batteries

12.50, 8.00 These components were important as they powered the robot. The price is moderate, but limited capacity and voltage sag under load reduce their value.

3

SPDT miniature toggle
switch

2.95 This component was useful as it allowed the robot to be powered on and off easily. The price is very low for the convenience added.

5

16×2 I²C LCD display | 12.95 | This component was important as it provided user feedback during operation and
helped with troubleshooting. The price is fair for its added clarity and usefulness.

4

1000 µF capacitor | 3.90 | This component was important as it smoothed voltage dips caused by the motors
and servos. The price is very low for resolving a key issue.

5

Dulux rust paint | 2.00 | This component was used purely for aesthetic purposes. The price is low, but it
contributed nothing to functional performance.

2

Average Rating 4.29

Table 2: Cost-benefit analysis

12

### 2.4 Improvements and Future Work

Several changes could be made to improve the robot’s performance and extend its real-world applicability. One straightforward improvement would be increasing the PWM duty cycle sent to the N20 geared DC motors, raising the average voltage and wheel speed to allow faster navigation and more collection cycles within the time limit. However, this would require refinements to the movement algorithm, as higher speeds would reduce the robot’s ability to stop quickly when an obstacle is detected.

To extend real-world applicability, more substantial changes would be required. First, the clamp mechanism would need redesigning, as its curved arms are specialised for spherical objects of a fixed size; real-world plastic waste varies significantly in shape, size, and rigidity, making a more versatile endeffector such as a soft robotic gripper better suited to irregular objects. Second, the current 9 V alkaline and AAA batteries lack sufficient capacity for extended real-world operation, so upgrading to a rechargeable lithium-polymer battery pack would improve runtime while reducing long-term costs and battery waste.¹⁴

### 2.5 Lessons Learned

Throughout the project, the design team developed a wide range of skills. On the technical side, the team learnt the basics of CAD modelling, electrical circuit design, soldering, and coding, all of which were essential to building the robot. On the non-technical side, the team developed strong project management and teamwork skills. Across the ten-week project, each member learnt how to be punctual, plan meetings, and communicate effectively in a semi-professional manner. A key outcome of the project was the design team’s improved ability in project planning and time management. This was particularly important in the waste sorting robot project, as tight deadlines and simultaneous subsystem development required careful scheduling. The team managed this using a Gantt chart. Overall, all these technical and non-technical skills can be applied to both future individual and group projects.

## 3 Conclusion

Overall, the final waste sorting robot successfully met the project’s performance objectives, autonomously sorting red, green, and blue balls representing HDPE, PET, and PP plastic types while avoiding yellow balls representing non-recyclable material, within the defined arena and in an operator-specified order. This was achieved while remaining within the 200 mm x 200 mm x 200 mm size constraint and the 50 AUD additional materials budget.

The final design is a self-contained, WALL-E inspired system divided into four subsystems. The robot is built around a dual-level PLA chassis with dedicated component mounts, cutouts for cables, and a detachable outer shell. It is driven by two front wheels and a rear caster wheel, allowing it to turn on the spot. The robot is controlled by an Arduino Uno, powered by two 9 V alkaline batteries and four AAA batteries, and uses several sensors to detect balls and obstacles, which it collects with a curved, servo-actuated clamp. The design is also highly cost-effective relative to its performance.

During final testing, the robot performed well, collecting 16 balls during the 10-minute time trial and placing the design team second in the waste sorting competition. This success demonstrates that autonomous robots can be applied effectively to plastic waste sorting, offering a way to improve recycling efficiency and sustainability on university campuses and in public spaces. Nevertheless, the current final design is highly specialised for ball collection and would require significant modification to be suitable for real-world plastic waste sorting. Ultimately, the project was a success, providing valuable insight into the application of automated systems in waste sorting.

## 4 References

[1] Cleanaway Waste Management Ltd., Recycling Behaviours Report 2024: Australians and Recycling: Attitudes, Behaviours and Outlook, May 2024. [Online]. Available: https://cleanaway2stor.blob.core.windows.net/cleanaway2-blob-container/2024/05/CWY_RBR2024_Report_7MAY2024 -FINAL.pdf. (https://cleanaway2stor.blob.core.windows.net/cleanaway2-blob-container/2024/05/CWY_RBR2024_Report_7MAY2024-FINAL.pdf) [Accessed: May 1, 2026].
[2] United Nations Environment Programme, “Plastic pollution,” UNEP. [Online]. Available: https: //www.unep.org/plastic-pollution. [Accessed: May 1, 2026].
[3] Arduino, “UNO R3,” Arduino Documentation. [Online]. Available: https://docs.arduino.cc/hardware/uno-rev3/. (https://docs.arduino.cc/hardware/uno-rev3/) [Accessed: May 1, 2026].
[4] PixyCam, “Color Connected Components,” PixyCam 2.1 Documentation. [Online]. Available: http s://docs.pixycam.com/wiki/doku.php?id=wiki:v2:color_connected_components. [Accessed: May 1, 2026].
[5] PixyCam, “Color Connected Components API,” PixyCam 2.1 Documentation. [Online]. Available: https://docs.pixycam.com/wiki/doku.php?id=wiki:v2:ccc_api. [Accessed: May 1, 2026].
[6] Arduino, “analogWrite(),” Arduino Documentation, May 9, 2025. [Online]. Available: https: //docs.arduino.cc/language-reference/en/functions/analog-io/analogWrite/. [Accessed: May 1, 2026].
[7] ElecFreaks, Ultrasonic Ranging Module HC-SR04 Datasheet. [Online]. Available: https://cdn.sparkfun.com/datasheets/Sensors/Proximity/HCSR04.pdf. (https://cdn.sparkfun.com/datasheets/Sensors/Proximity/HCSR04.pdf) [Accessed: May 1, 2026].
[8] D. Nedelkovski, “Ultrasonic Sensor HC-SR04 and Arduino – Complete Guide,” How To Mechatronics. [Online]. Available: https://howtomechatronics.com/tutorials/arduino/ultrasonic-sensor-hc-sr04/. (https://howtomechatronics.com/tutorials/arduino/ultrasonic-sensor-hc-sr04/) [Accessed: May 1, 2026].
[9] DIY Machines, “HC-SR04 Ultrasonic Sensor – What it is and how to use it,” YouTube. [Online]. Available: https://www.youtube.com/watch?v=1E4TDZC-xaY&t=101. [Accessed: May 1, 2026].
[10] Vishay Intertechnology, TCRT5000 Reflective Optical Sensor with Transistor Output Datasheet. [Online]. Available: https://www.vishay.com/docs/83760/tcrt5000.pdf. [Accessed: May 1, 2026].
[11] Instructables, “TCRT5000 Infrared Reflective Sensor – How It Works and Example Circuit With Code.” [Online]. Available: https://www.instructables.com/TCRT5000-Infrared-Reflective-Sensor-How-It-Works-a/. (https://www.instructables.com/TCRT5000-Infrared-Reflective-Sensor-How-It-Works-a/) [Accessed: May 1, 2026].
[12] FEETECH, FS90MG Micro 1.8 kg.cm Metal Gears Analog Servo Datasheet. [Online]. Available: https://www.gotron.be/media/files/Downloads/FS90MG.pdf. [Accessed: May 1, 2026].
[13] Phipps Electronics, “1602 16x2 HD44780 LCD Display with Soldered I2C Module – Support Documentation,” May 10, 2025. [Online]. Available: https://www.phippselectronics.com/support/1602-16x2-hd44780-lcd-display-with-soldered-i2c-module-support-documentation/. (https://www.phippselectronics.com/support/1602-16x2-hd44780-lcd-display-with-soldered-i2c-module-support-documentation/) [Accessed: May 1, 2026].
[14] Adafruit, “Voltages,” Li-Ion & LiPoly Batteries, Jul. 29, 2012, revised Jul. 8, 2025. [Online]. Available: https://learn.adafruit.com/li-ion-and-lipoly-batteries/voltages. [Accessed: May 1, 2026].

[15] Electronics Tutorials, “Capacitor Charge and Discharge.” [Online]. Available: https://www.electronics-tutorials.ws/capacitor/cap_2.html. (https://www.electronics-tutorials.ws/capacitor/cap_2.html) [Accessed: May 1, 2026].

## 5 Appendices

### 5.1 Source Code Links

Draft pre-final code (prefinal code v2.ino): View on Google Docs (https://docs.google.com/document/d/1BGou3gVNhyoJ-I85zxlT80wCSmkbmPXBK5kBOGmIc_8/edit?usp=sharing)

Final testing code (FINALTESTING.ino): View on Google Docs (https://docs.google.com/document/d/1ItQwgDLfk973PB1jUFH9qoTTOo4122GhGqnZm-5u4_U/edit?usp=sharing)

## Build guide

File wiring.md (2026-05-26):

# WALL-F Wiring

This document describes the final wiring used by `finalcode/FINALTESTING/FINALTESTING.ino`.

## Schematic

The final circuit schematic is available as a PNG preview:

```text
hardware/schematic/wall-f-schematic.png
```

The PDF reference extracted from the submitted final report is also included:

```text
hardware/schematic/wall-f-schematic-from-report-page.pdf
```

WALL-F schematic

The schematic matches the final report circuit diagram and should be read together with the pin mapping below. Editable KiCad source files will be added under `hardware/kicad/` once they are exported and checked.

## Arduino Pin Map

| Net | Arduino Pin | Module | Notes |
|---|---|---|---|
| MOTOR_A_DIR | D2 | MKRVRS motor driver | Direction input |
| MOTOR_A_PWM | D3 | MKRVRS motor driver | PWM / enable input |
| MOTOR_B_DIR | D4 | MKRVRS motor driver | Direction input |
| MOTOR_B_PWM | D5 | MKRVRS motor driver | PWM / enable input |
| SERVO_RIGHT_SIG | D6 | Right clamp servo | Servo signal |
| SERVO_LEFT_SIG | D7 | Left clamp servo | Servo signal |
| US_TRIG | D8 | HC-SR04 ultrasonic | Trigger output |
| IR_OUT | D9 | TCRT5000 IR sensor | Active LOW in final code |
| PIXY_SPI_SS | D10 | PixyCam 2.1 | SPI chip select |
| PIXY_SPI_MOSI | D11 | PixyCam 2.1 | SPI MOSI |
| PIXY_SPI_MISO | D12 | PixyCam 2.1 | SPI MISO |
| PIXY_SPI_SCK | D13 | PixyCam 2.1 | SPI clock |
| US_ECHO | A2 | HC-SR04 ultrasonic | Echo input, used as digital input |
| I2C_SDA | A4 | 16x2 I2C LCD | I2C data |
| I2C_SCL | A5 | 16x2 I2C LCD | I2C clock |

## Motor Driver Notes

The final code names the two motor output groups as A and B:

```cpp
const uint8_t DIR_A_PIN = 2;
const uint8_t PWM_A_PIN = 3;
const uint8_t DIR_B_PIN = 4;
const uint8_t PWM_B_PIN = 5;
```

Before publishing a final schematic, verify the physical left/right motor labels against the code's forward, backward, and spin helpers. If the robot drives correctly with the final code, preserve the physical wiring and document the channel mapping from the tested build.

## Power Architecture

Final build power sources:

| Rail | Source | Used For |
|---|---|---|
| VBAT_UNO_9V | 9 V alkaline battery | Arduino Uno barrel input |
| VBAT_MOTOR_9V | 9 V alkaline battery | MKRVRS motor supply |
| V_SERVO_AAA | 4xAAA alkaline pack | FS90MG servo power |
| V_LOGIC_5V | Arduino / regulated 5 V rail | PixyCam, LCD, logic modules |
| GND_COMMON | Shared ground | All modules |

All grounds must be common between the Arduino, motor driver, PixyCam, LCD, ultrasonic sensor, IR sensor, and servo battery negative.

## Capacitors

The final design used two 1000 uF capacitors to reduce voltage dips:

- One across the Arduino 9 V supply terminals.
- One across a main power rail for transient smoothing.

Show these in the schematic as labelled components, for example `C1 1000uF` and `C2 1000uF`.

## PixyCam SPI Warning

The PixyCam uses Arduino SPI pins. Avoid assigning other devices to D10-D13 unless they are intentionally sharing the SPI bus.

The final design moved:

- Ultrasonic TRIG to D8
- Ultrasonic ECHO to A2
- IR sensor output to D9

This avoids conflicts with the PixyCam SPI connection.

## Servo Supply Warning

The two clamp servos should not be powered directly from the Arduino 5 V pin. The final build used a separate 4xAAA pack for the servo rail, with the servo ground tied to common ground.

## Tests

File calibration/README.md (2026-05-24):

# Calibration Sketches

These sketches are placeholders for recalibrating WALL-F on rebuilt hardware.

They intentionally use `xxxx` values where measurements are required. Replace those placeholders before uploading a calibration sketch to the Arduino.

## Sketches

| Folder | Purpose |
|---|---|
| `servo-clamp-calibration/` | Find open and closed servo angles for both clamp arms |
| `motor-turn-calibration/` | Measure 90-degree, 180-degree, and 360-degree turn timings |
| `ultrasonic-distance-test/` | Verify HC-SR04 readings and obstacle threshold |
| `ir-clamp-test/` | Confirm active LOW clamp detection |
| `pixy-signature-check/` | Verify PixyCam signatures and block positions |
| `base-return-calibration/` | Measure base size thresholds for return/deposit stopping |

The final competition sketch keeps the tested values used during the 10-minute run.

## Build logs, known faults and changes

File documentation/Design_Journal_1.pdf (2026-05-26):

## Design Journal 1

### DESN1000 - Week 4

### UNSW zID: xxxxxxx

### Page Count: 48

## Contents

1 Design Process | 1
2 Teamwork | 20
3 Reflections | 35

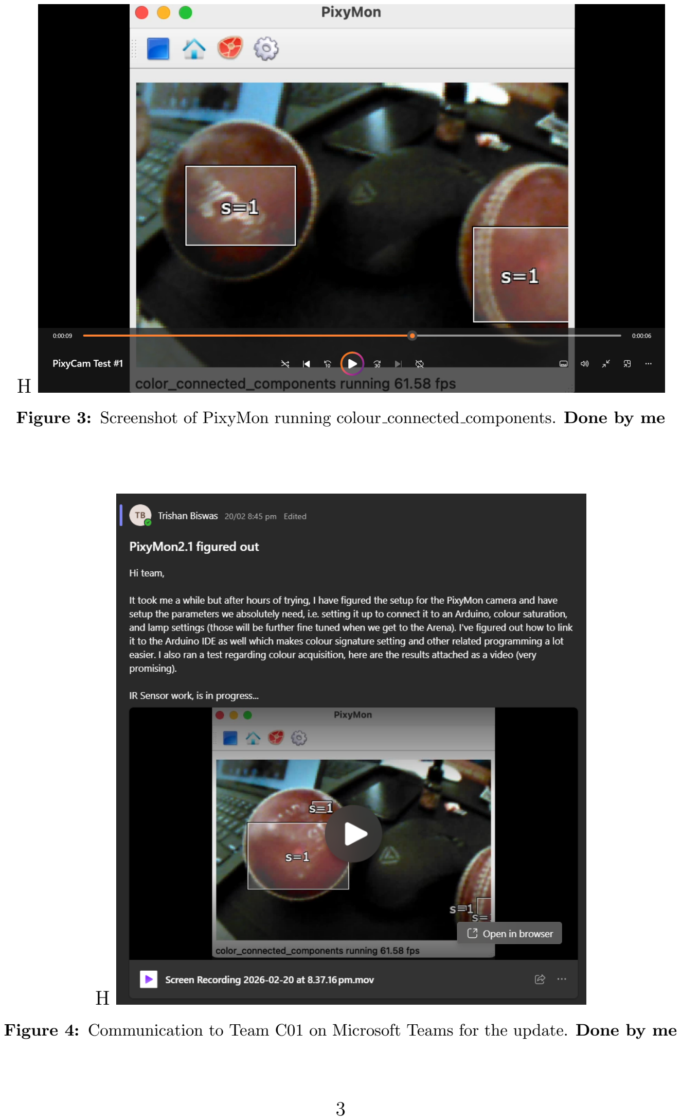
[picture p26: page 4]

H

Figure 3: Screenshot of PixyMon running colour connected components. Done by me

H

Figure 4: Communication to Team C01 on Microsoft Teams for the update. Done by me

### 1.1.3 Entry 3 (21/02)

On the 21st of February, I began the action item that I took initiative in setting up regarding setting up a “component to subsystem layout” for all the kit items we are provided with to inform everyone what each component’s role is within the robot system. I approached this by individually mapping key kit components to subsystems and defined its role within the robot.

Subsequently, I utilised LucidSpark to produce a component role mindmap to visualise these component groupings by subsystem to have a clear system overview. This is particularly useful for those people unfamiliar with these components in Team C01.

Ultimately, I think this exercise prefaced the full scope of the robot’s overall design and architecture whilst confirming that no critical parts were missing or unaccounted for. See Figure 5 below for the LucidSpark mindmap I created.

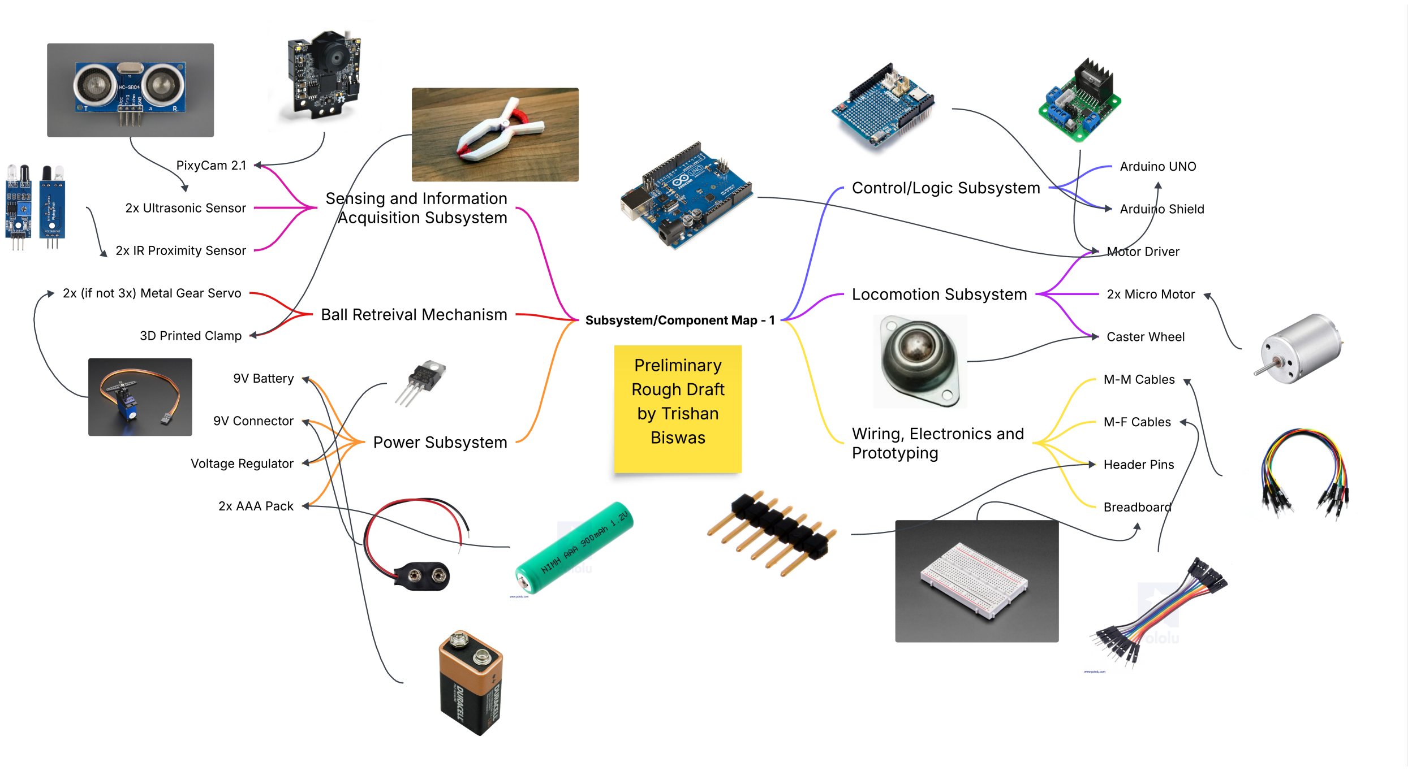
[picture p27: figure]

Figure 5: LucidSpark mindmap with subsystem to component layout. Done by me

### 1.2 Week 2

### 1.2.1 Entry 4 (23/02)

For the very first entry of week 2, I will discuss how I designed a formal sensor testing plan for the IR sensor and the Ultrasonic sensor along with running and designing a simulation of the test on TinkerCAD circuits. This was all done before Week 3 to have a solid plan before running the tests physically in Week 3.

Having run a preliminary PixyCam test, it only makes sense to configure and run tests with the other two sensors too. However, as of now we haven’t been provided with enough details regarding the functioning of the sensors and how to code with it on the Arduino IDE. Hence, I did my own independent research by watching various video tutorials and reading up on important information regarding the setup (i.e. which pin on the ultrasonic sensor means what and where is it connected to, how to program with it and receive distance calculations). The sources I used to learn these are listed in the “Sources” section.

After learning and gathering information regarding the setup, I ran a simulation of the ultrasonic sensor first on TinkerCAD. See Figure 6 below for the ultrasonic sensor simulation.

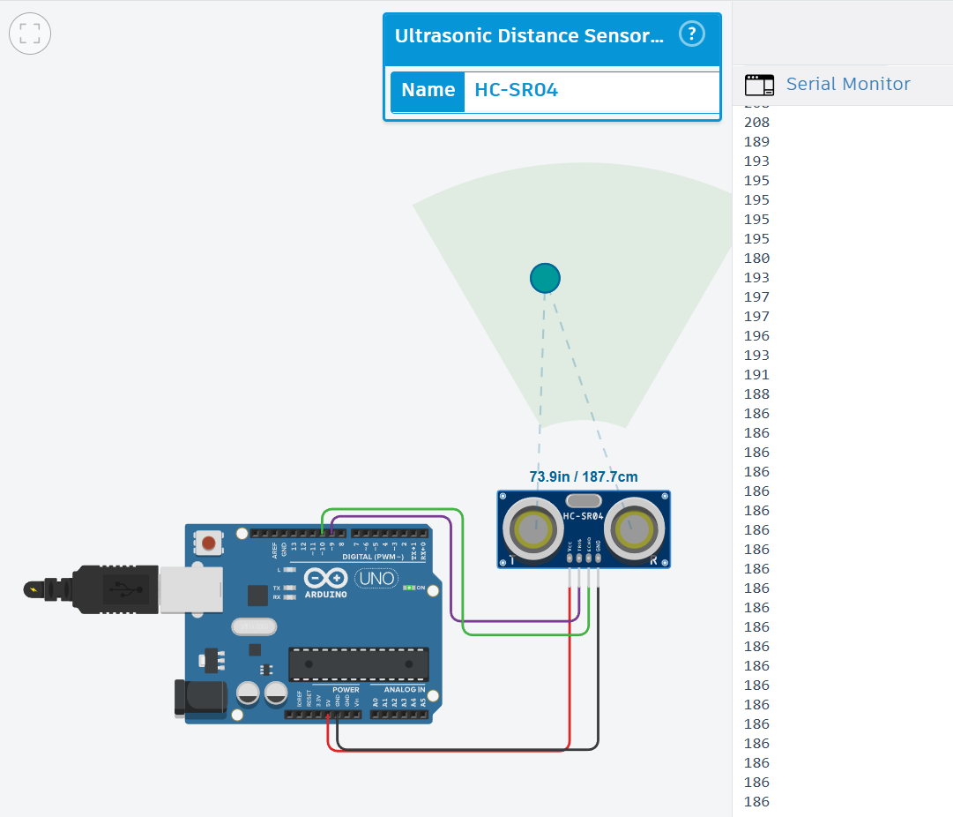
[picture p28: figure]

Figure 6: HC-SR04 Sensor simulation ahead of Week 3 physical sensor test. Made by me

I then calculated the percent error in measured distance against the actual distance by running multiple tasks, and they all seemed to be off by ˜1.0-1.7cm from the actual measurement. Hence, with the value in Figure 6, the percent error was calculated as follows:

187.7 − 186.0
187.7
- 100% = 0.91% ≈ 1%

Which is still very accurate and negligible in the use case of ball range finding.

Subsequently, I designed and ran another simulation to test the IR Obstacle/Proximity sensor and verified it’s performance by placing an obstacle in front of it and connecting an LED (with a 200Ω resistor connected to another digital pin which would have a power outputted (to light the LED) by the Arduino when a LOW signal is passed through the IR Sensor (i.e. there is an object detected by the sensor). See Figure 7 below for the IR sensor simulation.

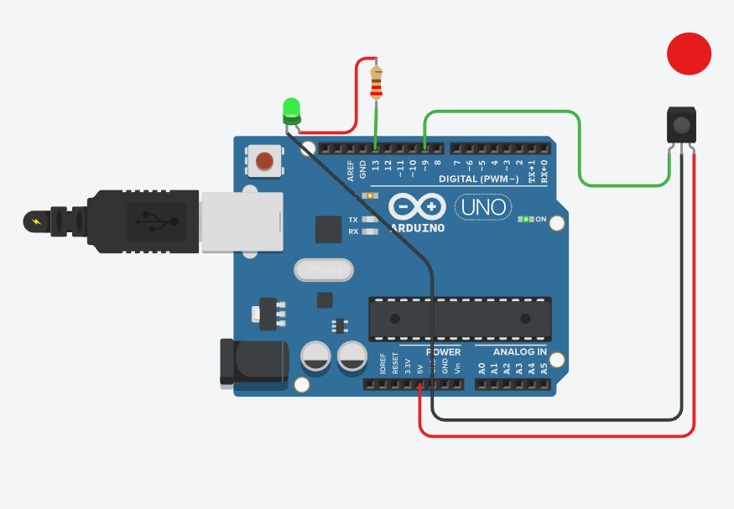
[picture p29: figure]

Figure 7: IR Sensor simulation ahead of Week 3 test, green LED is on (object detected). Made by me

### 1.2.2 Entry 5 (26/02)

For entry 2 of week 2, the main agenda from the mechanical subgroup’s side was to run a test on the metal gear servo while linked to the Arduino UNO. Hence, on the 26th of Feb the mechanical subgroup leader Franklin and I (programming leader) set up a Microsoft Teams meeting setting up the Arduino UNO, wiring the servo pins to the UNO, and coding the “sweep” on the IDE.

The metal gear servo was taken by Franklin and I assisted in the coding side of things while we were on call. See Figure 8 for evidence of the meeting.

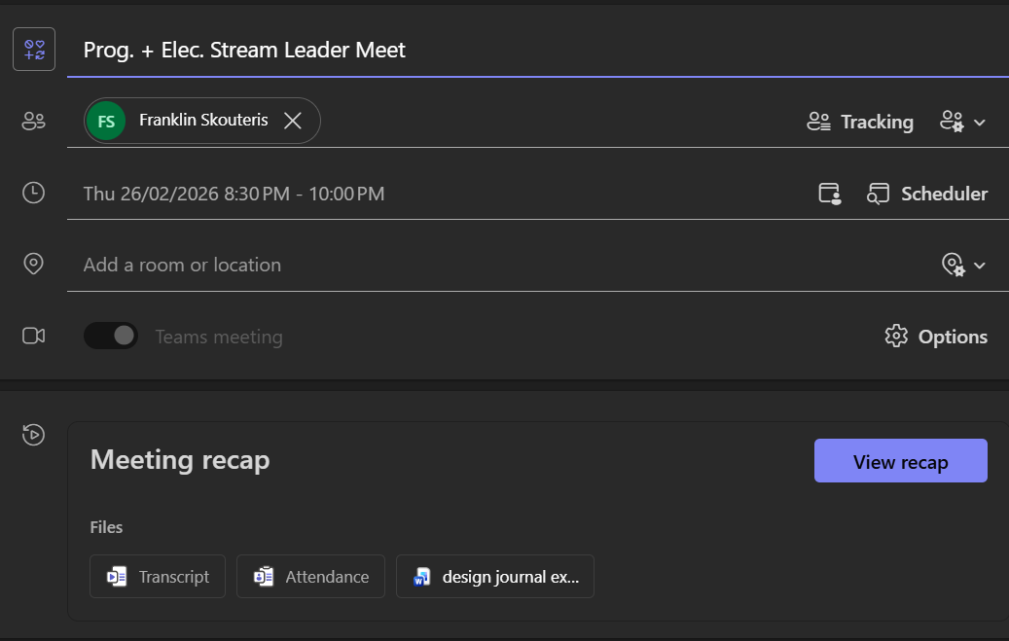
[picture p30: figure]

Figure 8: Meeting organised for preliminary servo sweep test. Organised by me & Franklin

In this meeting, we wrote and ran a servo “sweep” test directly on the Arduino IDE using one metal gear servo attached appropriately. Then, the code swept the servo through a bunch of angle ranges to determine whether it has a limit. Subsequently, there was, as we initially tested angles beyond 180◦and a full 360◦
rotation, we were expecting a continuous motion or an extended rotation beyond 180◦
. However, the discovered that the servo has a maximum range of motion (ROM) of 180◦
. This was a critical finding for the servo aided clamp mechanism design. That is, the claw must be programmed within 0◦

to 180◦
range to open and close.

The next steps now are to figure out and map servo sweep angles to an “open” and “close” configuration on the clamp. See Figure 10 below for an image of the servo sweep code. In it, the servo rotates from 0° to 180° and back in 20° increments, with a 100 ms delay per step. The highlighted rows indicate key configuration lines while the annotations describes the function of each statement.

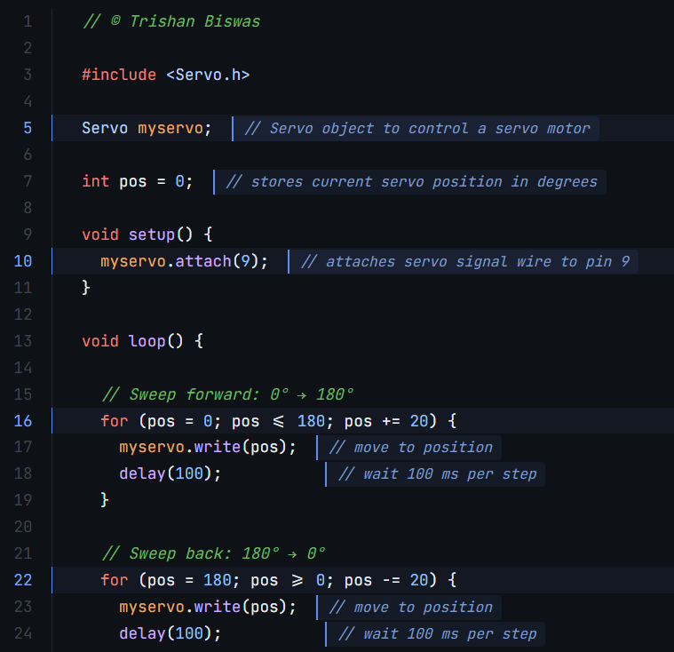
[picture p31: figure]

Figure 9: Servo sweep test sketch, coded by me and Franklin.

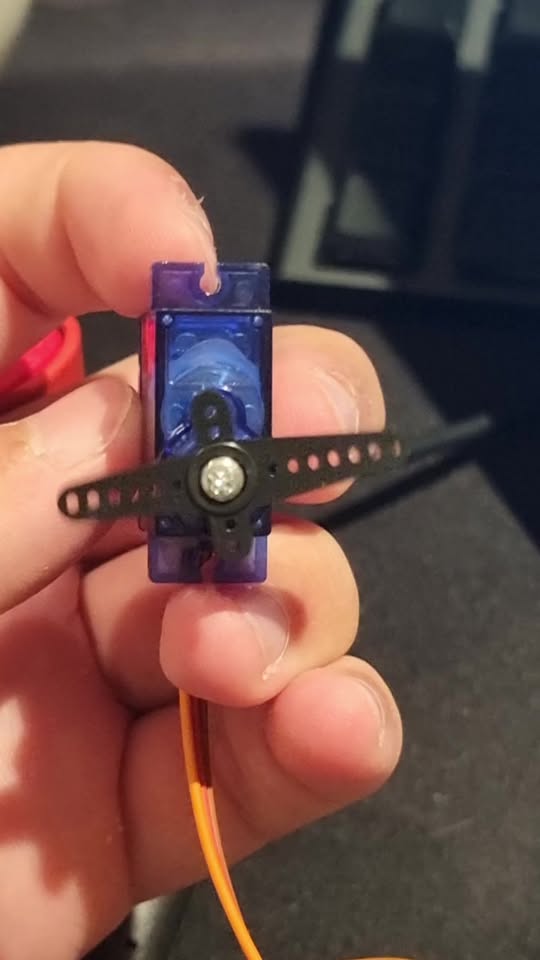
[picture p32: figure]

Figure 10: Servo sweep test. Image of the physical test. Taken by Franklin

### 1.2.3 Entry 6 (27/02)

For Entry 6, I will walk through how I generated and completed my parts for the Crazy Eights and what each of my eight ideas were for my self assigned subsystem. That is, for the sensor integration subsystem. I generated eight distinct concepts under time limits with rough sketches for each of them. I would say that each concept explored a unique approach to positioning each of the sensor components like the PixyCam, the Ultrasonic, and the two IR sensors relatives to the main body of the robot and the ball collection system.

The eight concepts that I generated were:

- Elevated head vision - this involved the Pixycam mounted high on a raised angular mount (Inspired by Wall-E), an ultrasonic sensor front and centre, and two lateral (side mounted) IR sensors
- Ground level targeting - here, all the sensors are front mounted at a low height with two IR sensors angled 15 degrees inwards for a smaller detection zone to place the ball right in the middle.
- Dual sensor fusion front plate - here the PixyCam is angled downward, with an ultrasonic sensor right below it, then, it was two IR sensors angled 15◦
toward the center
line for ground level obstacle and ball detection.
- Pan servo camera concept - in this one, the PixyCam is mounted on a metal gear servo with a 120◦
sweep for a wider field of view, an ultrasonic sensor front centre, and two IR sensors on the corners (oblique). This maximises not only the FOV but also coverage in terms of obstacles.

- Side by side stereo layout - the Pixycam and ultrasonic sensors are mounted side by side here for a compact yet offset design for the face plate. This was made as a layout for the bell enclosure ball collections system.
- Funnel guided intake sensing - the IR sensors are positioned at key trigger zones on the edges of the funnel prongs, the PixyCam is mounted 5◦downward statically.
- Tiered sensing zones integrated - this is by far the best design as rated by all team mates. Here, the PixyCam is on a servo (Zone 1 and 2), the ultrasonic sensor (zone 2) relays info to the PixyCam, and the two flank IR sensors are obstacle detectors (zone 2), linked to the locomotion subsystem.
- Minimalist face place - this idea aimed for peak minimalism as I planned an acrilyc face plate that houses all sensors statically. This has the same layout as Concept 3 but is fully enclosed in a detachable faceplate with no protruding parts.

See Figure 11 below for my very own Crazy Eights sensor integration subsystem concept generation.

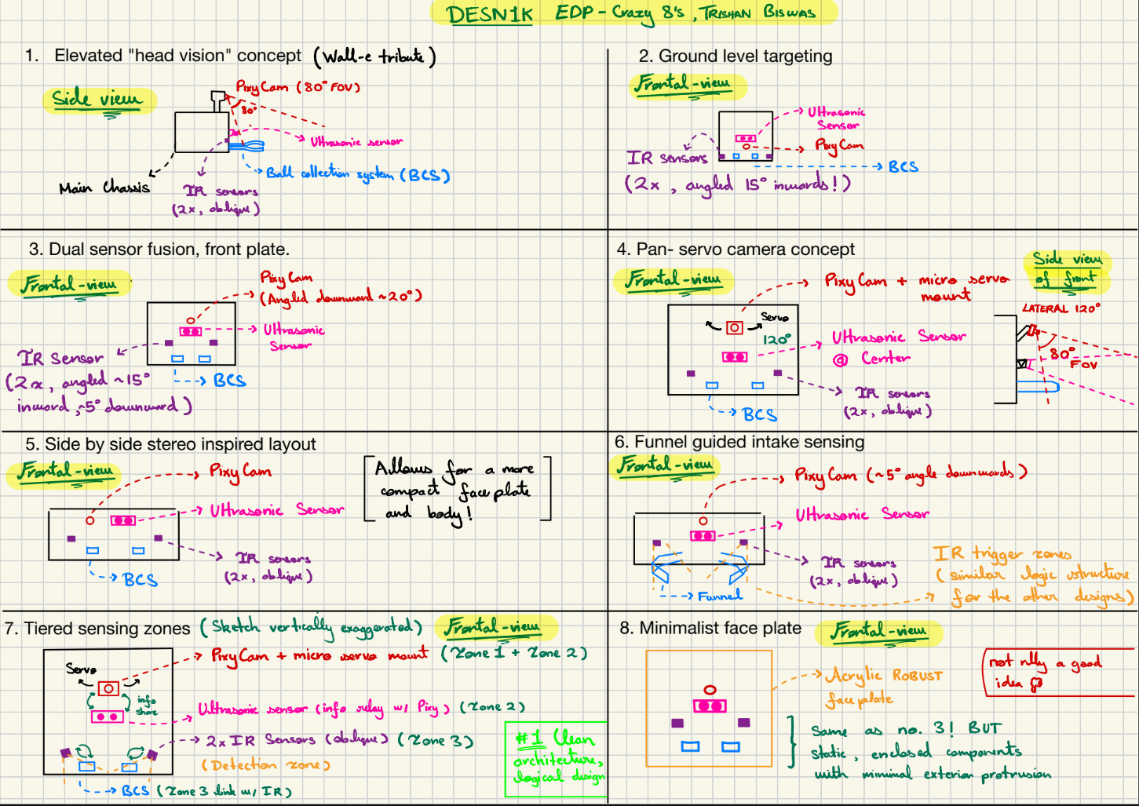
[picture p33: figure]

Figure 11: Sensor integration/layout concepts for my crazy eights. Made by me

### 1.3 Week 3

### 1.3.1 Entry 7 (02/03)

Entry 7 of the design process section was logged at the start of Week 3. This entry is going to cover how I carried out physical sensor and also evaluated the performance of the HC-SR04 ultrasonic sensor and the IR obstacle sensor. I also will showcase how I troubleshot a readout inaccuracy on the ultrasonic sensor through my coding skills.

I began the physical sensor tests by first connecting the ultrasonic sensor to the Arduino UNO and wrote a distance measurer code which constantly reads out distance in the serial monitor of the IDE every 300ms. Then, I configured the setup as follows: I placed the red foam ball (given to us) around 15-16cm away from the sensor (measured with a ruler). Subsequently, I ran the program on the IDE, and I read the serial monitor outputs. At first everything seemed to be fine as it was outputting values within the range of 15-16cm. However, I observed occasional spikes in readings, for an example, see Figure 12

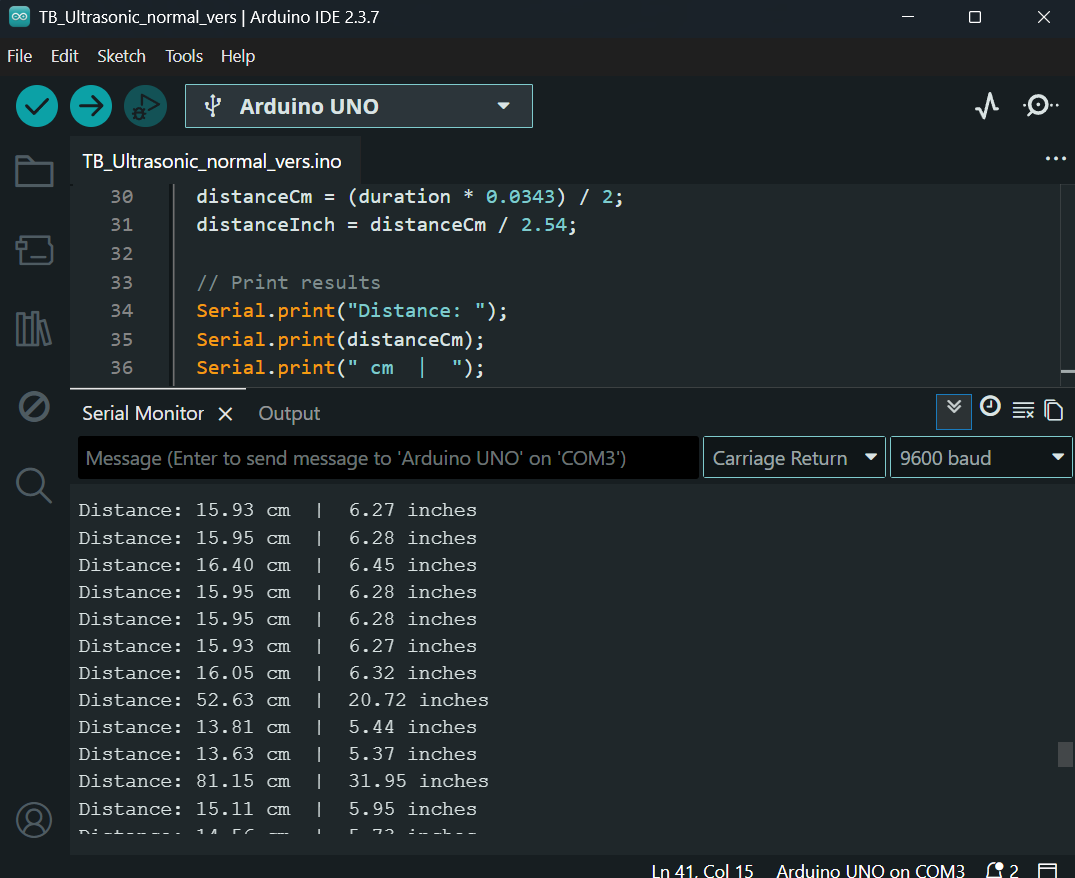
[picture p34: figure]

Figure 12: Inaccurate distance readouts due to background clutter with initial code. Made by me

I diagnosed this as an issues cause due to signal interference and NOT the hardware because it was a source of random error and not systematic. Hence, I amended the code by implementing a “median filter” that I made in the code to discard outlier values that spike and ensure that the logic device gets only the accurate readings. See Figure 13 for the original code (left) and the median filter version (right).

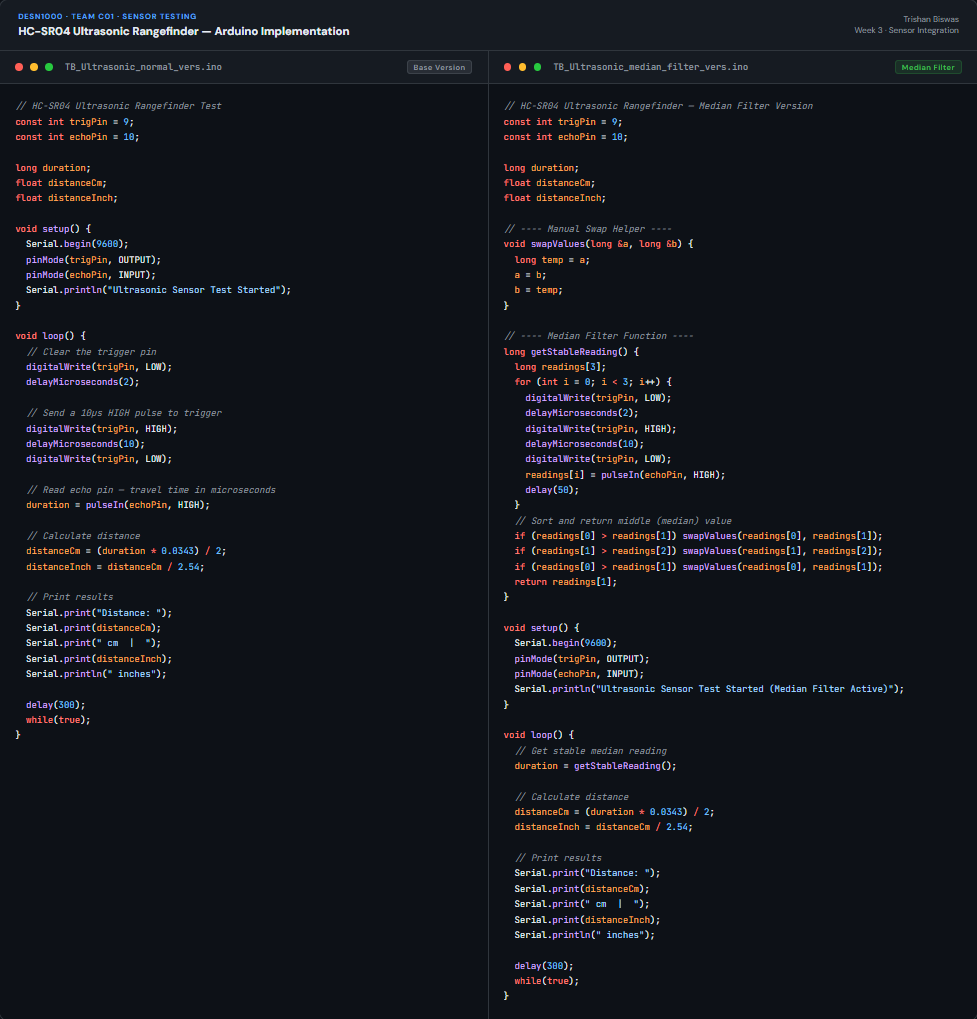
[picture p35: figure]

Figure 13: Code for ultrasonic distance measurement (read line above figure). Made by me

After applying the median filter, the readings were far more accurate and also consistent. This confirmed that the sensor was actually reliable in the use case that I’m planning to use this for - for approach ditance measurement to communicate to the Arduino and relay it to the motor driver. See Figure 14 below for just the median filter amendment I applied and continue reading for an explanation of how it works.

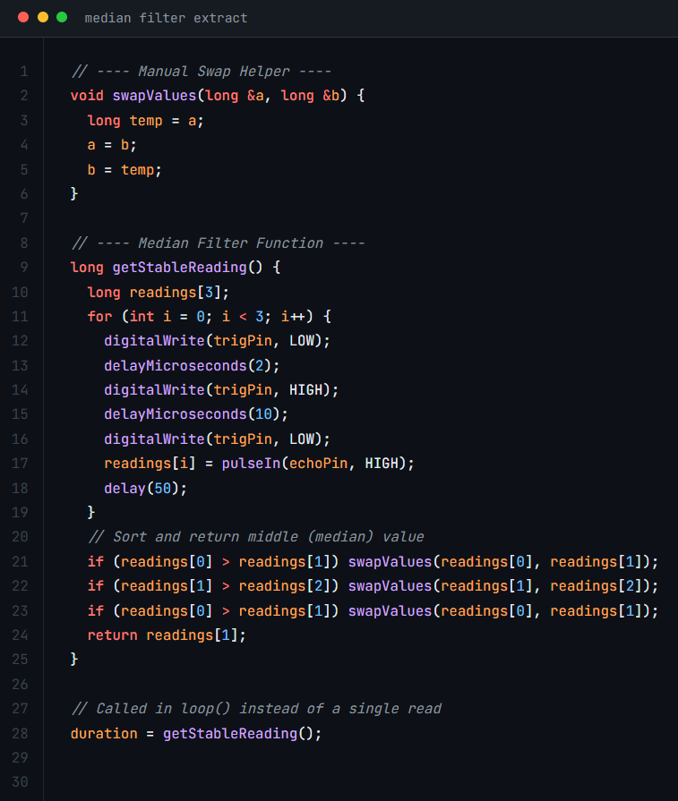
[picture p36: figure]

Figure 14: Median filter code (just the filter part extracted). Made by me

What the filter does essentially is that is takes 3 consecutive readings. So instead of firing it once, the “getStableReading()” fires a distance measurement three times. Then “swapValues()” does a simple bubble sort on the array of three values received and only then, the middle (median) value is returned “readings[1].” Furthermore, any “spike” in the values sits at the bottom of the array and is discarded. Furthermore, see Figure 15 for an image of the Ultrasonic sensor test video I shared on Teams.

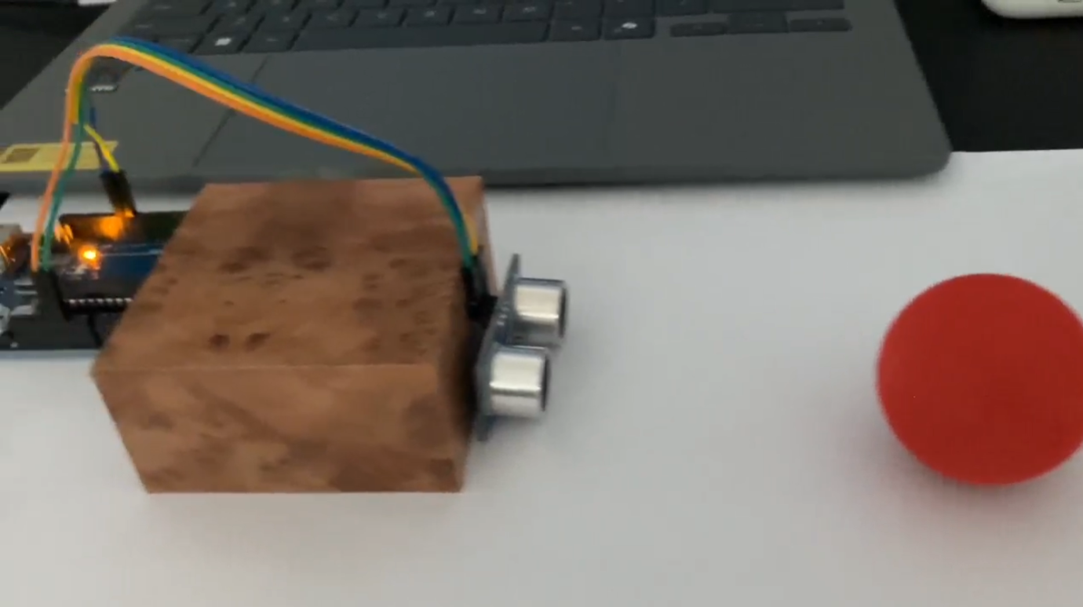
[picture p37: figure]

Figure 15: Picture of ultrasonic test video shared on Teams. Made by me

Next, the IR Sensor testing. This was quite straightforward as the IR sensor module is quite easy to set up with the Arduino and to code on the to output ”No object detected” or ”Object detected” on the Serial Monitor. I knew the IR sensor was working well not only due to the fact that the serial monitor was reading out ”Object detected,” but rather because the LED on the IR module turns on. I also tweaked the manual distance screw on the module to test it at a slightly longer distance. The code is as follows in Figure 16 below for the IR sensor and the picture of the video that I shared on teams follows that Figure in Figure 17.

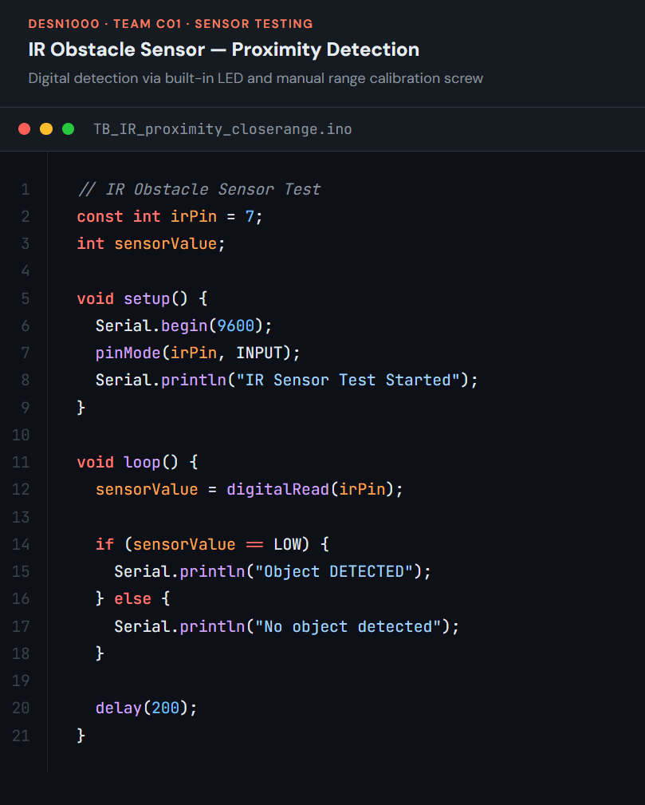
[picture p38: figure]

Figure 16: Code for the IR sensor, LOW/HIGH is detected/undetected. Made by me

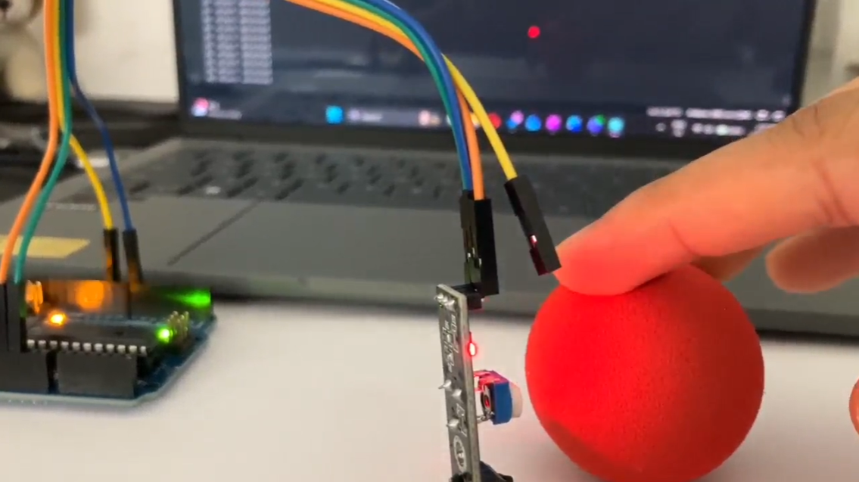
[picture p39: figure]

Figure 17: Picture of ultrasonic test vid I shared on Teams. Made by me

### 1.3.2 Entry 8 (05/03)

Entry 8 will purely consist of EDP work. As that is the main priority due to this assessment task being weighted 20%. Hence, for this entry I will be discussing the progression of our problem statement and also our team’s LucidSpark mindmap and the morphological chart generated by Franklin for our three chosen concept generation tools.

The problem statement was first brainstormed as a team based on information from Wendy’s W2 lecture. Subsequently, we continually edited it as a team by providing input. And finally, once we prepared it enough, we went to Brielle and Wendy to receive feedback, upon receiving the feedback. Jesse and Yusuf incorporated them into a final problem statement that is very solid, well defined, and specific. Here is the progression of it:

“Design and construct an autonomous robot that identifies and sorts plastic waste into PET, HDPE and PP categories while avoiding non-recyclable materials. The primary stakeholders are the UNSW Environmental Sustainability Team, along with students and staff, who require more accurate and efficient sorting of plastic waste to prevent contamination of recycling streams and improve recycling effectiveness. The robot must be a single, self-contained unit with dimensions no greater than 200 mm × 200 mm × 200 mm

→ Redrafted as a team

Design and build an autonomous robot that navigates the arena, identifies and collects the operator-specified recyclable plastic (red = HDPE, green = PET, blue = PP), avoids yellow (non-recyclable) items and obstacles, and returns the collected item to the team base. The primary stakeholders are the students and staff, who require this robot to remove waste across campus and improve recycling accuracy. The robot will also operate as a single and self-contained physical unit, start within the designated starting zone, have initial dimensions no greater than 200 mm × 200 mm × 200 mm, and use no more than $50 of additional materials beyond the provided kit.”

→ Final one

Design and construct a prototype of an autonomous robot that identifies and sorts plastic waste into PET, HDPE and PP categories while avoiding non-recyclable materials. The primary stakeholders are the UNSW Environmental Sustainability Team, along with students and staff, who require a more accurate and efficient sorting solution over manual sorting, to reduce contamination of recycling streams and improve recycling effectiveness. The robot must be a single, self-contained unit with dimensions no greater than 200 mm × 200 mm × 200 mm.

These were achieved using the 5Ws scaffold, by following the marking rubric closely and identifying things that are missing or need rephrasing on our own. Followed by, a final presentable version which was informed by clear feedback from Brielle and Wendy in response to our prepared questions for them.

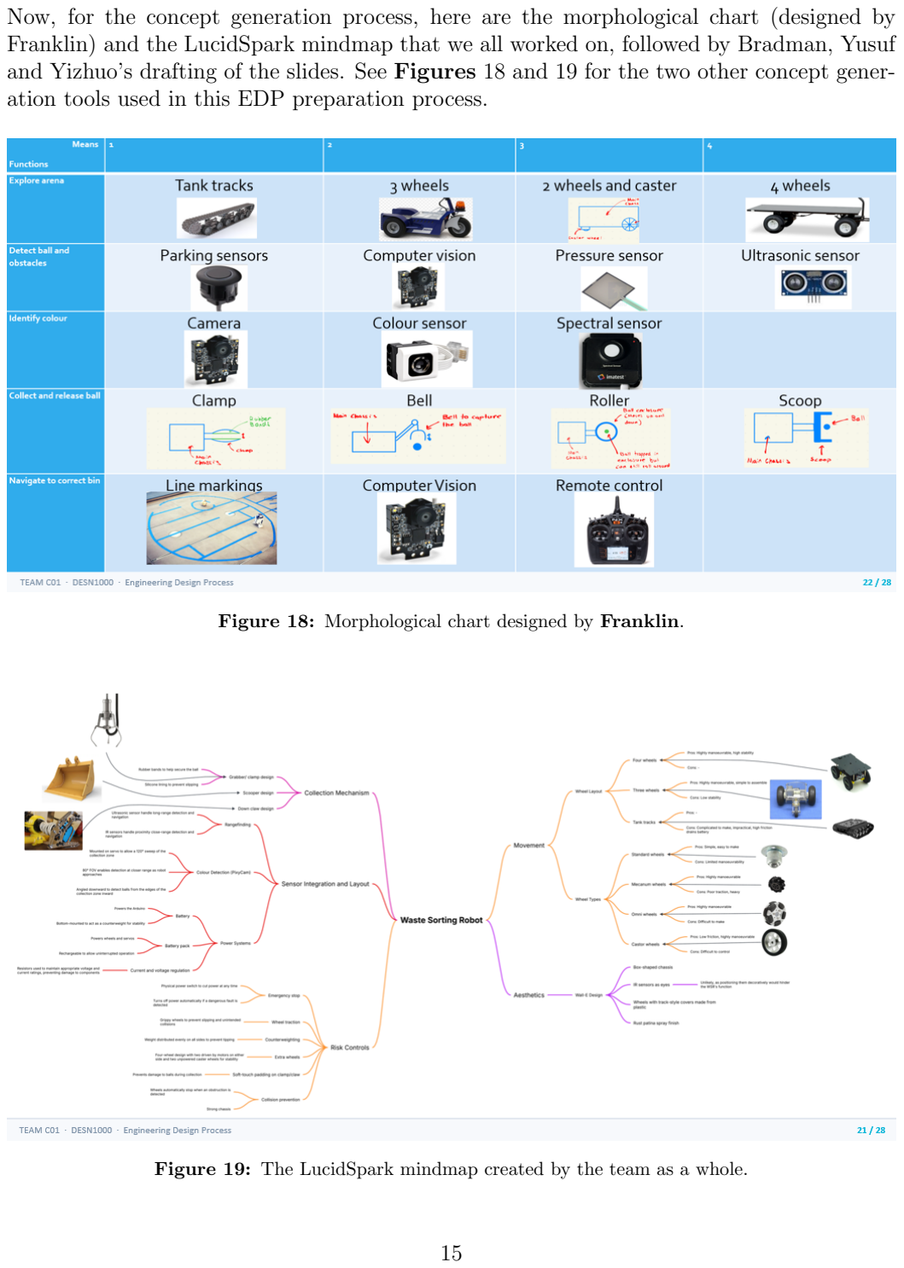
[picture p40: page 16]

Now, for the concept generation process, here are the morphological chart (designed by Franklin) and the LucidSpark mindmap that we all worked on, followed by Bradman, Yusuf and Yizhuo’s drafting of the slides. See Figures 18 and 19 for the two other concept generation tools used in this EDP preparation process.

Figure 18: Morphological chart designed by Franklin.

Figure 19: The LucidSpark mindmap created by the team as a whole.

### 1.3.3 Entry 9 (07/03)

Based off of our previous meeting, we established that all team memebers will work independently over the weekend on their EDP presentation sections assigned to them. For me, that was the concept solutions section. That meant, I had quite a bit to get done. Firstly, I convened with the subgroup leaders on Friday to narrow down concept solutions based off of the discussions we hard in relation to our concept generation tools as a team in our last meeting. We met via Teams on multiple days across the weekend. And these following base concept solutions are what we concluded:

- Concept 1: a robot with a passive funnel scoop with an enclosure to store the balls. It’s sensor layout would be static mounted but angled appropriately with a high mounted PixyCam, one middle ultrasonic sensor, and two lateral mounted IR sensors. The wheels would be triangular tank tracks (like Wall-E).
- Concept 2: a robot with a vertical “bell” enclosure which descends upon the ball (actuated by DC motor) and securely holds it. With a 4 wheel, 2 rear caster wheel configuration with FWD. And the sensor layout would be angled and mounted in an offset manner to account for the ball collection system in the middle with no ultrasonic sensor and two front IR sensors for ball positioning.
- Concept 3: a servo aided and rubber band/rubber lined clamp design to grip the ball securely. It would have a 4 (regular) wheel layout with FWD. And the sensor layout would be a PixyCam mounted high angled downward on a sweeping servo to maximise FOV and two ultrasonic sensors front centre for ball and ball cluster rangefinding along with two flank IR sensors. Additionally for aesthetics, a Wall-E head will be printed along with a Wall-E chassis (minus the tank tracks).

Now, the next steps for me is to sketch them with annotations and labelling. I will begin sketching the concepts on Sunday and aim to have them finished by Monday’s team meeting. After this meet, I began working on 2 minute long my EDPP script, I drafted and asked team members for feedback and eventually produced a final version shown in Figure 20

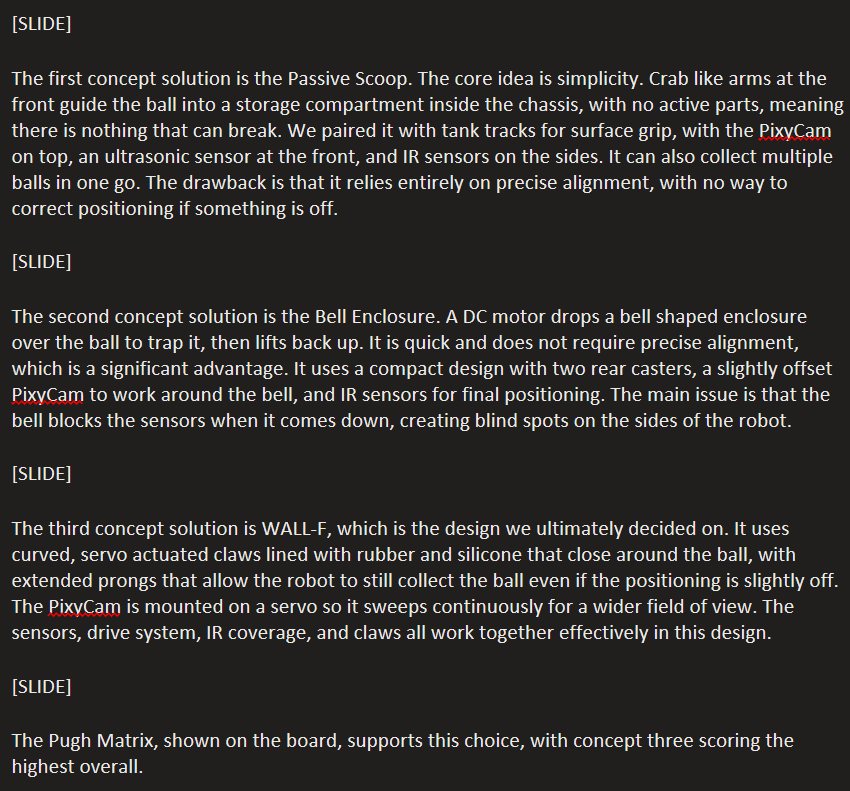
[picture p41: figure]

Figure 20: My final EDPP script uploaded to team OneNote for the concept solutions section.

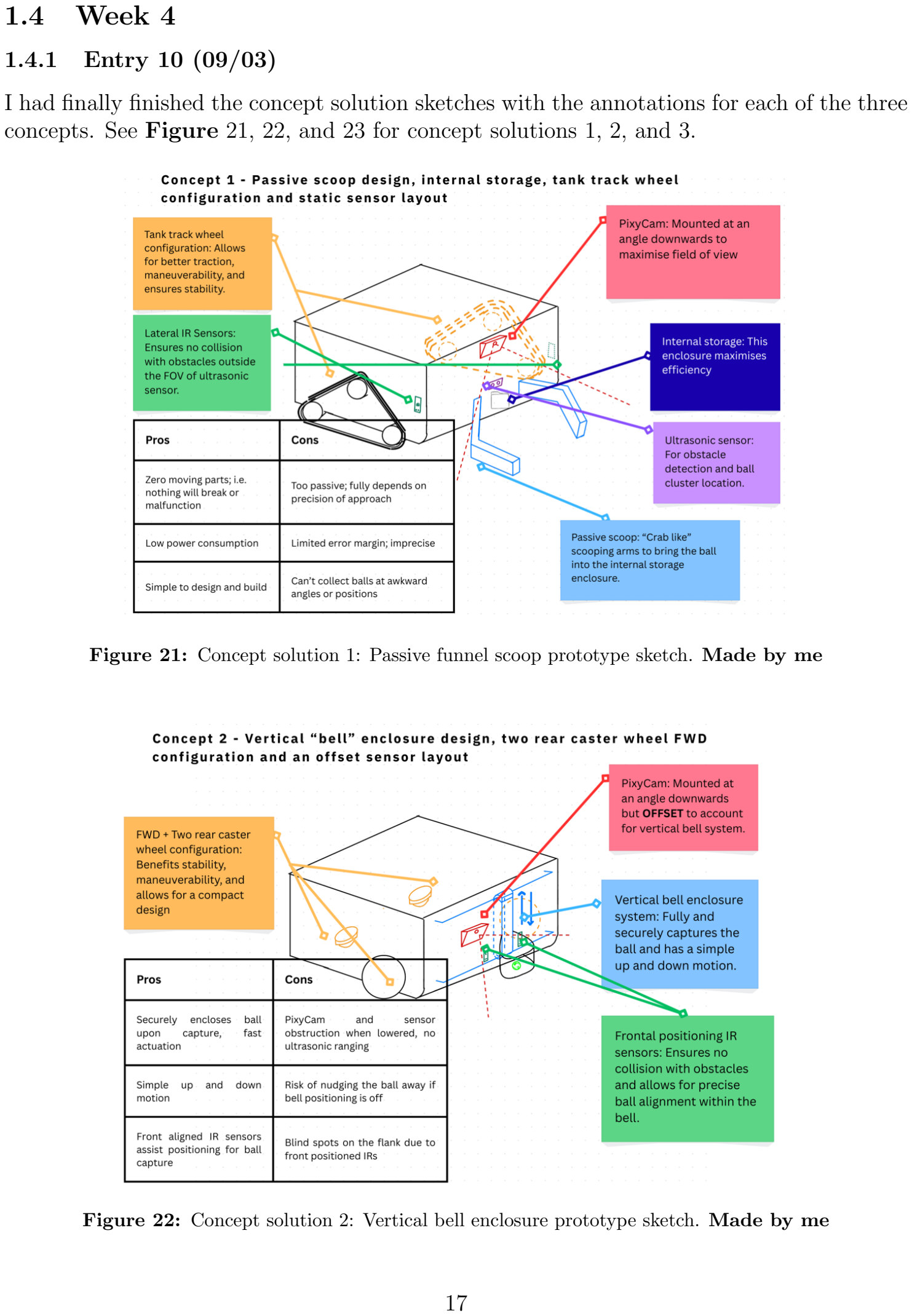
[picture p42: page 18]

### 1.4 Week 4

### 1.4.1 Entry 10 (09/03)

I had finally finished the concept solution sketches with the annotations for each of the three concepts. See Figure 21, 22, and 23 for concept solutions 1, 2, and 3.

Figure 21: Concept solution 1: Passive funnel scoop prototype sketch. Made by me

Figure 22: Concept solution 2: Vertical bell enclosure prototype sketch. Made by me

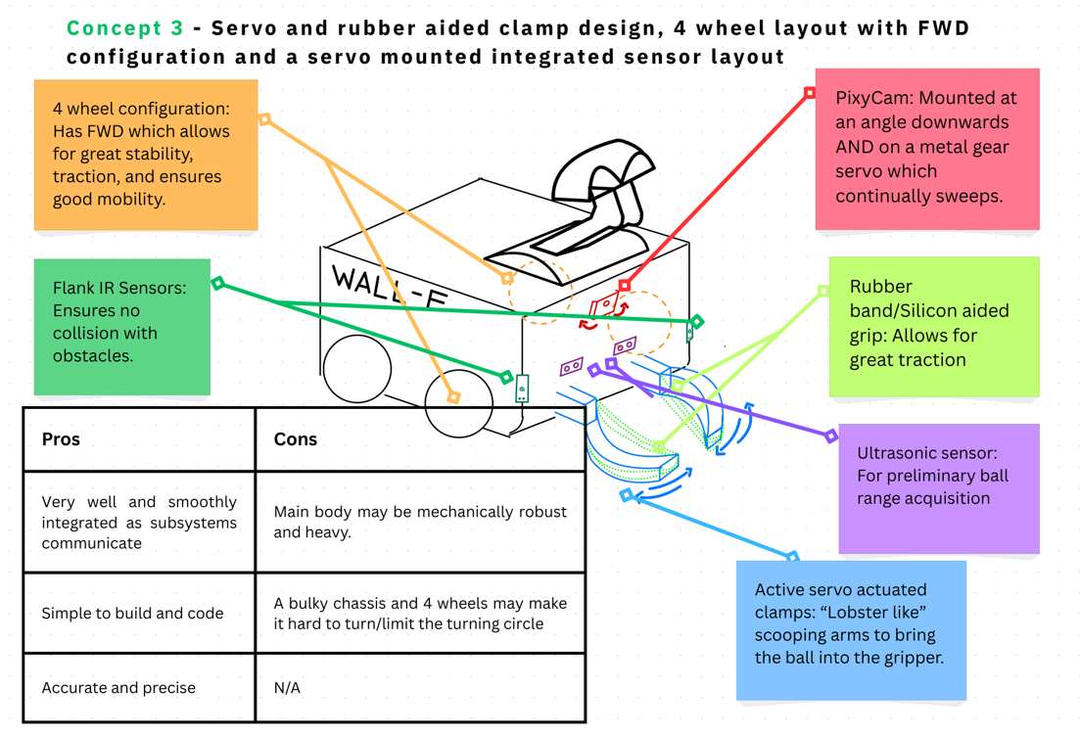
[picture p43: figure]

Figure 23: Concept solution 3: Servo aided clamp prototype sketch. Made by me

Having completed all the concept sketches with appropriate labelling and annotations, I have met my goal established from the last entry and I am right on schedule for the team set EDP deadlines. This meant that I could show up to our Monday group meeting with solidified concept solutions sketched out for an evaluation by the whole team. This process involved the whole team utilising the “Pugh Matrix,” which is a ranking system that involves settings a “baseline” or a standard, and whether each concept has a characteristic above or below the required standard. I took initiative and created the Pugh matrix before hand. Having done through this as a whole team, the results concluded that Concept 3 is the most mutually favoured solution to go ahead with. See Figure 24.

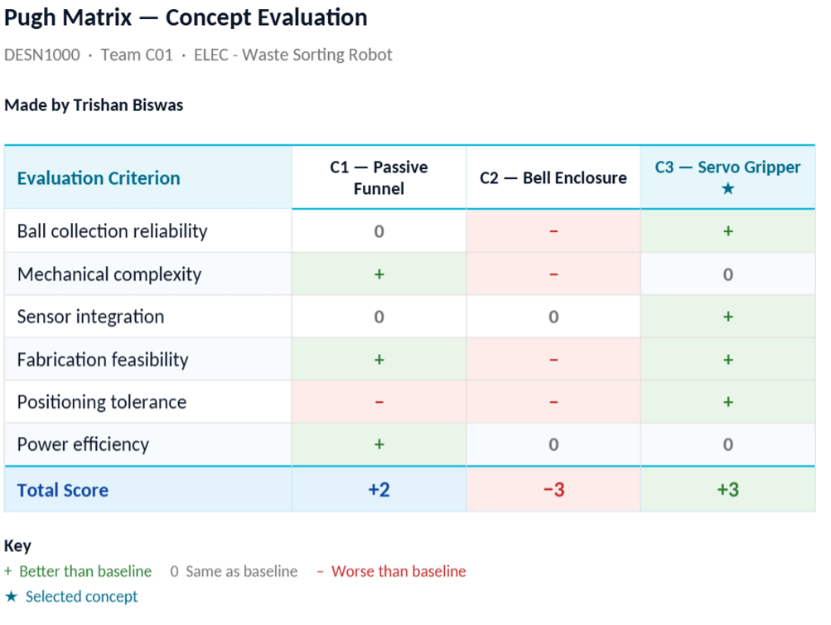
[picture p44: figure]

Figure 24: The Pugh matrix after the team and I evaluated the concepts. Made by me

### 1.4.2 Entry 11 (12/03)

For entry 11, which is based off of 12th March’s group meeting where we continued our EDP presentation scripts and speaking it individually and timing it for further script refinement. We also aimed to lock everything in within this group meeting such as the script, make a cohesive script which combines everyone’s scripts and we add stage directions, transitional sentences and practice our delivery very roughly before a proper and complete rehearsal on Saturday and Sunday. Furthermore, we planned to thoroughly prepare every single member on slides other than theirs over the weekend in preparation for the Q&A segment where anyone can be asked on anything in the presentation.

See Figure 25 below for a portion of the complete EDP Presentation script that we all collaborated on and contributed to (but mainly Jesse).

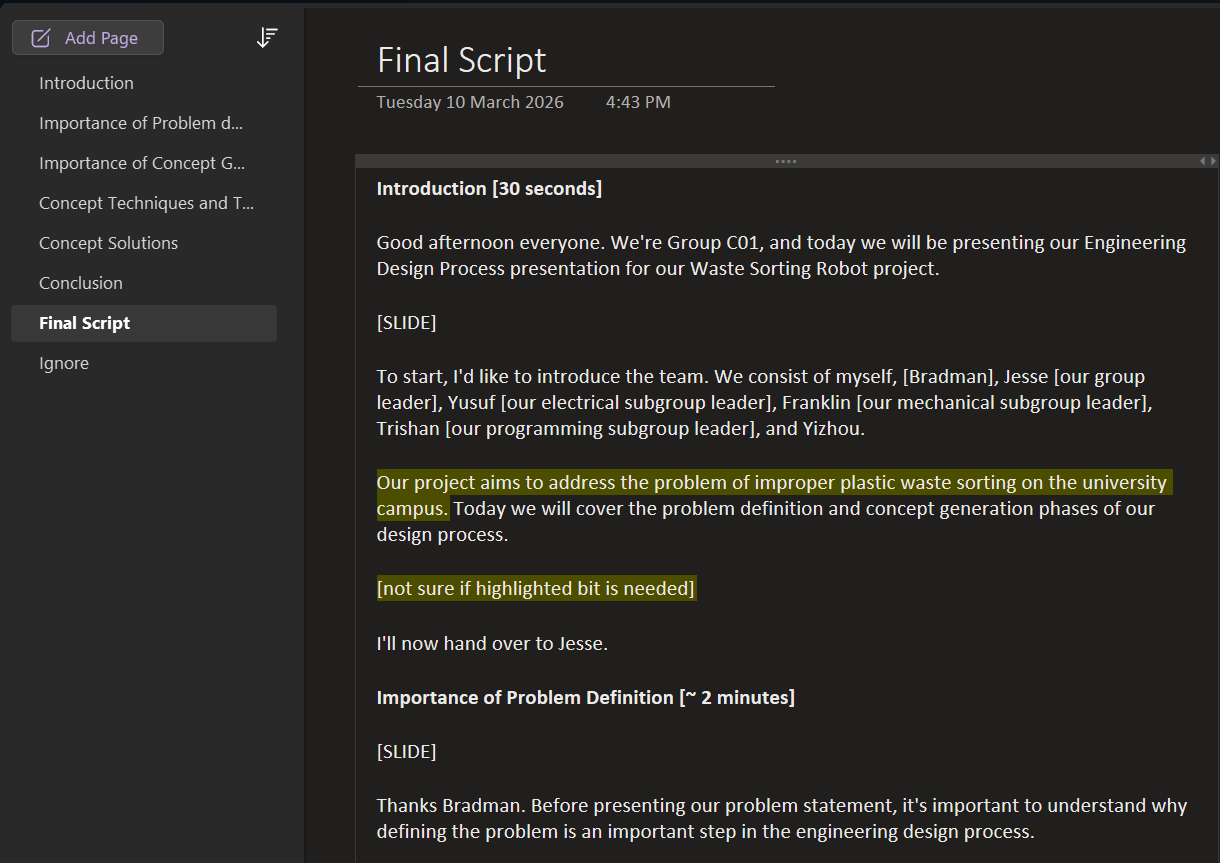
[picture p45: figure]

Figure 25: A portion of the final script. With transitional sentences, stage directions, and each section’s script.

Furthermore, in terms of the refinement of the EDP slides, it was also done during the session, led by Bradman. We originally went from a dark themed aesthetic which he deemed as unclear in terms of readability. Thus, we switched to a calmer and more legible white colour scheme and increased the font sizes of the text. Furthermore, we strictly aimed to keep text absolutely minimal but concise.

## 2 Teamwork

### 2.1 Week 1

### 2.1.1 Entry 1 (18/02)

As it is Week 1, in terms of teamwork, we conducted an informal team meeting on the 18th of February where we discussed everyone’s strengths and areas of comfort regarding the key components of this project (i.e. coding, mechanical, and electronics). As of now there have been no formal role assignments, as we are waiting for our first mentor meeting. Furthermore, in the informal meeting we established that we are all aiming for a High Distinction. And, that we all seem to be on the same page in terms of course outcomes and the direction that the project will be heading. Concluding the meeting, there is a general sense of subgroups, however, we have not finalised a leader yet.

Time | 18/02, 13:00-14:00
Location | [In person UNSW Main Library]
Attendance | All members were present.
Agenda | • Discuss ball retrieval mechanism options • Explore wheel configurations and layout • Discuss team strengths and comfort areas and evaluate possible subgroup leaders • Gain a general idea on project and course outcomes and the effort willing to be put in
Meeting Summary | • Preliminary clamp/gripper designs discussed and eval-uated • Wheel configurations compared (3-wheel vs 4-wheel) and layout options (caster rear wheels or normal rear wheels) • Informal discussion of individual strengths in conjunc-tion with establishing that we all are aiming for a HD in this course and project.
Decisions Made | • Claw/gripper mechanism identified as preferred re-trieval approach • 3-wheel and 4-wheel configurations both still under con-sideration • Formal role assignments deferred to next session after mentor meeting

Action Items
- All members will reflect on preferred roles prior to next meeting
- Trishan will look into PixyCam colour detection capabilities before further sensor work and planning.
- Team to review and walk through Design Journal 1 guidelines
- Team will aim to complete Makerspace Induction and Soldering badge before/during the day of first mentor meeting.

### 2.1.2 Entry 2 (20/02)

Time | 19/02, 15:00 – 17:00
Location | ElecEng224
Attendance | All members + Mentor were present.
Agenda | • Determine team roles and jobs for the weekend • Establish recurring meeting times • Acquire Soldering Badge
Meeting Summary | • Team roles formally established across four subgroups: Documentation, Electrical, Programming, Mechani-cal/Chassis • Weekly internal meetings set for Mondays at 12:00pm in the library • All members obtained Soldering Badge
Decisions Made | • Weekly internal meetings on Mondays at 12:00pm in the library; additional meetings online as needed • Roles established across Documentation, Electrical, Programming, and Mechanical/Chassis subgroups

Action Items
- Trishan to research programming with all sensors and set up a component layout
- Franklin to measure Arduino casing dimensions and plan the Arduino UNO layout with chassis
- Bradman to refine preliminary ball collection system designs.
- Jesse to research and compare wheel design options
- Yusuf awaiting more information on the electrical component of the design but continuing individual contributions to the project.
- Yizhuo to be in charge of documentation and research.

Significant progress was made in our very first mentor meeting as subgroups, team leader, and subgroup leaders were selected and finalised early on. This was very good as it gave everyone a sense of direction early, which is crucial to the smooth development of our robot. See the table below for the team roles and responsibilities assigned.

Role | Responsibilities | People
Documentation | • Maintain notebook • Record meeting notes • Track design changes | • Jesse • Yizhuo • Bradman
Electrical | • Wiring and circuit layout • Sensor integration • Troubleshoot electrical issues | • Yusuf (Subgroup Leader) • Franklin • Trishan
Programming | • Write and test code • Ensure accurate autonomous op-eration • Ensure seamless integration of all subsystems • Debug software issues | • Trishan (Subgroup Leader) • Franklin • Yusuf

Mechanical
& Chassis
Design
- Design robot structure
- CAD modelling
- Assembly and fabrication
- Mechanical testing and adjustments
- Franklin (Subgroup Leader)
- Bradman
- Jesse
- Yizhuo

### 2.1.3 Entry 3 (21/02)

Time | 20th-21st Feb
Location | Informal Conversations / Independent
Attendance | All members contributing independently
Agenda | • Individual progress on assigned tasks • Team updates via Microsoft Teams
Meeting Summary | • Trishan (me) researching kit items and components, and their roles. Furthermore, creating the LucidSpark sub-system map. • No formal meeting held, progress tracked through Teams announcements and informal check ins and con-versations • Franklin progressing on clamp design refinement and Arduino Casing on Fusion • Bradman refining wheel types, clamp and functionality options • Jesse contributing to documentation and leading weekly comms, due to the leader role.
Decisions Made | • Component roles and subsystem assignments finalised • LucidSpark adopted as shared visual tool for system mapping

Action Items
- Trishan to begin sensor programming research ahead of Week 2
- Franklin to use component layout to inform chassis dimension planning
- Bradman to finalise wheel config recommendation for next team meeting

### 2.2 Week 2

### 2.2.1 Entry 4 (23/02)

Time | 23/02, 12:00 – 13:00 and 15:00 – 17:00
Location | Main Library and ElecEng224
Attendance | All members were present.
Agenda | • Review prelab content and share previous week’s progress • Go over EDP requirements as a group • Establish team workflow, deadlines, and communication structure

Meeting Summary
- 4 wheel configuration formally selected for superior stability
- Claw clamp selected as preferred ball collection mechanism
- EDP structure reviewed: problem definition, conceptual design importance, annotated sketches
- Discussed HD requirements for EDP and formulated questions for mentor
- Trishan troubleshot and resolved PixyCam compatibility issues on macOS
- Franklin designed Arduino mounting plates and smaller component mounts
- Bradman created EDP PowerPoint scaffolding

Decisions Made
- 4 wheel configuration selected as final locomotion design
- Claw clamp selected as ball collection mechanism
- Goal oriented subgroup workflow with end of week synthesis and constant check ins
- Deadline structure: physical tasks 1 week ahead, writing 3 to 4 days ahead, hard deadline 1 day before submission
- Work ahead of time principle adopted to prevent time crunch
- Jesse to run weekly workload questionnaire flagging if members have too much or too little on
- Progress tracking via Excel and Gantt chart
- EDP slides to address marking criteria directly; verbal delivery can be more flexible
Action Items
- Begin wheel fabrication early
- Finalise component mounting positions
- Get Arduino operational
- Begin EDP presentation, address marking criteria directly in slides

### 2.2.2 Entry 5 (26/02)

Time | 26/02 12:00 – 13:45
Location | Main Library and ElecEng224
Attendance | All members were present.
Agenda | • Draft problem statement using lecture slides and record-ing from Wendy’s W2 lecture • Discuss and narrow down 3 concept generation tools we’re going to use • Plan important questions for Brielle and possibly Wendy regarding problem statement • Complete, agree upon, and discuss TEAM CON-TRACT with Brielle

Meeting Summary
- We used the 5Ws framework to scaffold the problem statement, then filled in details including key constraints
- We then planned to seek feedback from our mentor and Wendy directly on the current problem statement, regarding what is working and what is missing from it.
- Then, we all discussed and narrowed down concept generation tools to a morphological chart, LucidSpark mindmap, and Crazy Eights.
- Then, the crazy eights task was assigned per subsystem: Trishan (sensor integration), Bradman (wheel design), Jesse and Franklin (gripper design), Yusuf and Yizhuo (aesthetics)
- We walked through the team contract in detail, establishing guidelines and safety nets in case of worst case scenarios.
Decisions Made | • By the end, morphological chart, LucidSpark mindmap, and Crazy Eights confirmed as concept generation tools • The 5Ws adopted as the framework for problem state-ment formulation along with identifying constraints and following the marking criteria. • We agreed to refer to the team contract in the event of worst case scenarios or to resolve disputes. And we said that we’d all adhere to the expectations we set on it with Brielle
Action Items | • After today, each member must complete their own Crazy Eights for their assigned subsystem by the 1st of March. • Seek feedback from mentor and Wendy on problem statement before finalising and incorporate the feedback into the problem statement. • We must begin populating morphological chart and mindmap and have it completed by Week 3 Monday.

### 2.2.3 Entry 6 (27/02)

Time | Nearing the end of W2
Location | Independent / Microsoft Teams
Attendance | All members contributing independently
Agenda | • Firstly, we all will review each member’s contribution to their assigned subsystem’s Crazy Eights. • Then, to continue contributing individual subsystem ideas to a shared LucidSpark mindmap that I created and shared. • Franklin will independently make a morphological chart that we will all work on to decide concept solutions.

Meeting Summary
- (It was very good to see that) All members were working on their Crazy Eights and doing multiple trials to refine it.
- Trishan – sensor integration
- Bradman – wheel design
- Jesse and Franklin – clamp/gripper design
- Yusuf and Yizhuo – aesthetics
- Jesse noted that all members contributed to the LucidSpark mindmap for their respective subsystems by the set deadline (team set, not the formal deadline)
- Furthermore, Franklin produced the morphological chart covering sensors, wheels, clamp type, and navigation.
- Bradman collated these ideas and put them on the EDP PowerPoint presentation

Decisions Made | • Crazy Eights, LucidSpark mindmap, and morphological chart confirmed as the three concept generation tools for the EDP presentation. • We narrowed down that the 4 best crazy eights design will be going on the presentation. • We all decided that Bradman would be in charge of the PowerPoint presentation and updating it (along with Jesse). • While we get more info regarding the EDP, Trishan will be conducting sensor tests in Week 3 soon. • Franklin will be continuing on the mechanical side of things leading the subgroup towards wheel design.
Action Items | • Complete the MindMap before W3 Tuesday at the lat-est, everyone must continue contributing to it. • Hold an informal meeting with the whole team to review the Morph chart and shortlist the best ideas. • Eventually hold another informal between subgroup leaders to finalise concept solutions based on the MindMap, Crazy eights, and Morph Chart. With, a final Pugh Matrix ranking of the three draft solutions to shortlist the FINAL chosen concept solution.

### 2.3 Week 3

### 2.3.1 Entry 7 (02/03)

Time | 02/03, 12:00 – 13:45
Location | Main Library
Attendance | All members were present.
Agenda | • We should briefly review each other’s Crazy Eights sub-missions • Main agenda is to refine the problem statement as a group and draft/re-draft multiple times • We must prepare good questions for Brielle/Wendy re-garding the Problem Statement

Meeting Summary | • All of the team members reviewed and discussed each other’s Crazy Eights across all the subsystems. And we shortlisted 4 of the best. • Then, the problem statement was edited multiple times with input from all members to produce a refined version ready for feedback from Brielle or Wendy • We prepared questions for Brielle and Wendy regarding the problem statement • Then we went over the LucidSpark mindmap we com-pleted as a team and we agreed that images need to be added for clarity. So it is not yet fully complete.
Decisions Made | • Problem statement version prepared to present to Brielle and Wendy for feedback • We planned that some images must be added to Lu-cidSpark mindmap for improved clarity by Wednesday at the latest. • The best Crazy Eights Designs that were chosen were Franklin, Jesse, Yusuf and Trishan’s designs that are going on the presentation.
Action Items | • We shuld finalise and lock in the problem statement by Thursday after feedback. • We must review the morph chart and shortlist best ideas across subsystems as a team (if not subgroup leaders) • We should aim to have three concept solutions defined by end of Week 3 or start of Week 4
Time | 02/03, 16:00 – 17:00
Location | ElecEng224
Attendance | All members were present.
Agenda | • We must present the current problem statement draft for feedback • Ask prepared questions regarding problem statement content and structure

Meeting Summary | • We presented refined problem statement to Brielle and Wendy and received feedback on what to add or adjust. • From Brielle, we need to remove any constraints within the problem statements that are not necessary. • From Wendy, we need to add a “when”. As in, when is the project required to be completed by? And further clarity is required on the “who” part. As in, who are the specific stakeholders/consumers at play.
Decisions Made | • Thus, we aimed to have the problem statement updated, based on the feedback by Thursday this week.
Action Items | • Jesse and Yusuf to incorporate Brielle and Wendy’s feed-back into the final problem statement, and have a proper “final” one ready. • We should all proceed with concept solution develop-ment before the end of Week 3 in order to have 3 fully fixed concept solutions by W4.

### 2.3.2 Entry 8 (05/03)

Time | 05/03, 12:00 – 13:45
Location | Main Library
Attendance | All members were present.
Agenda | • We all walk through and discuss the morph chart, mindmap, and (briefly) the Crazy Eights as a team for shortlisting concept solutions. • We make enough notes and suggestions for subgroup leaders to generate three distinct concept solutions. • We must assign ownership of concept finalisation and sketching for the EDP presentation • Read through our locked in problem statement. • IMPORTANT: to assign every member a specific section of the EDP for them to work on over the week-end.

Meeting Summary
- The team went through the morph chart and the LucidSpark mindmap together, along with a brief revisit and discussion of the Crazy Eights designs.
- Enough input was given by everyone for subgroup leaders to take to narrow down three concept solutions and eventually refine it to one.
- Trishan has been assigned to sketch, annotate, and label all three concepts for the EDP presentation slides.
- Over the weekend, subgroup leaders must shortlist the concept solutions by end of Week 3
- The whole team must complete/ have some verbal input into the Pugh Matrix by start of Week 4.
- End of Week 3 is reserved for individual work on everyone’s EDPP scripts
Decisions Made | • As discussed above. And for the EDP roles are: • Jesse and Yusuf – Importance of problem statement • Importance of concept generation (technical and finan-cial risk) – Yizhuo • Importance of concept generation (Innovation and per-formance) – Bradman • Concept generation tools – Franklin • Concept solutions – Trishan
Action Items | • Franklin, Trishan, and Yusuf to finalise the three con-cepts concretely. • Trishan must make annotated concept sketches for the EDP slides • All subgroup leaders will shortlist the best ideas over the weekend via Teams/informally. • Everyone HAS TO begin drafting individual EDP scripts by end of Week 3 and finalise by Wednesday Week 4.

### 2.3.3 Entry 9 (07/03)

Time | 06/03 – 08/03
Location | Independent work / Microsoft Teams
Attendance | All members contributing independently
Agenda | • Each member continuing work on their individual EDP presentation section to completion and prepare script. • Subgroup leaders will shortlist and finalise three base concept solutions • Trishan to begin concept sketches, labelling, annotation, and Pugh Matrix
Meeting Summary | • No formal meeting was held as progress is being co-ordinated informally via OneNote and the PowerPoint across the weekend • Subgroup leaders informally met via Teams to shortlist three final concept solutions from the team discussion and key inputs from members defined on 05/03 • Trishan began sketching all three concept solutions for the EDP slides. The annotations and labelling are sup-posed to be completed by Week 4 Monday. • All members worked independently on their respective EDP sections.
Decisions Made | • The three final concept solutions shortlisted and con-firmed by subgroup leaders
Action Items | • Trishan will complete concept sketch and the respective annotations by Week 4 Monday • All members will continue refining their individual EDP sections and creating a script to memorise and present to the team • The whole team will start the Pugh Matrix together in the Week 4 meeting.

### 2.4 Week 4

### 2.4.1 Entry 10 (09/03)

Time | 09/03, 12:00 – 13:45
Location | Comp Lab on Level 2
Attendance | All members were present.
Agenda | • We have to review each other’s EDP presentations, work, and scripts and brief the team on each other’s sections briefly before a full briefing later on in W4. • Main agenda is to complete the Pugh Matrix as a team • Based on results, we have to select a final concept solu-tion to go ahead with. • Continue with script memorisation and streamlining the presentation and its coherence (Bradman and Jesse in charge for this).

Meeting Summary
- In this meet, each member briefly presented their EDP section to the rest of the team for a brief review and feedback session.
- Trishan presented the completed concept sketches with full annotations briefly.
- The entire team evaluated all three concept solutions together and informally completed the Pugh Matrix.
- Concept 3 (the Servo gripper or “WALL-F” prototype) was formally selected as the final design based on the Pugh Matrix outcome.
- The Pugh Matrix was updated and prepated to go in the EDP PowerPoint presentation.
- The next steps for each member’s EDP section was discussed. Mostly just memorising, presenting and timing

Decisions Made | • Concept 3 selected as the final robot design be-cause it scored the highest across the various criteria in the Pugh Matrix • Bradman and Jesse in charge to refine the PowerPoint and make it look good and coherent • Trishan in charge of timing when we run through a draft presentation. • Yizhuo and Bradman in charge of introduction and con-clusion • Yusuf in charge of sources/bibliography
Action Items | • Everyone must continue refining and rehearsing their individual EDP sections in their own time. We should all time it too. • We should finalise the EDP PowerPoint and make it ready for submission by the end of Saturday, W4 (One day before deadline).

### 2.4.2 Entry 11 (12/03)

Time | 12/03, 12:00 – 13:45
Location | Computer Lab
Attendance | All members were present.
Agenda | • We reviewed and trimmed each member’s individual script by asking them the timing on their speech and modifying the script accordingly • We all collaborated to write transitional sentences be-tween sections, led by Jesse • We then combined all scripts into one cohesive master script with stage directions. • We all worked towards finalising and refining the EDP slides. We aimed to ensure that it is ready for a full submission after Saturday’s morning rehearsal. Led by Bradman

Meeting Summary
- We first trimmed each member’s individual script and reviewed it collaboratively to improve conciseness and the overall flow of the master script
- Jesse led writing transitional sentences for each section to handover to the other. We wanted to ensure that the delivery was cohesive across all speakers.
- By the end of the meeting, a master script was produced which comvined all sections with slide change directions and speaker cues.
- We gave some special attention given to Yizhuo and Bradman’s intro and conclusion sections to ensure that there is a smooth opening and closing.
- Finally we reviewed the EDP slides and finalised the aesthetics. This was mainly led by Bradman.
Decisions Made | • The master script has been finalised and confirmed as everyone’s point of reference to practice the presentation and look over others’ sections • The EDP presentation was locked in following final re-view by the team leader Jesse on Saturday.
Action Items | • We decided that all members must rehearse their indi-vidual sections independently before Saturday where we will have a morning rehearsal session and an in person session on Sunday. Following us coming to the campus early on Monday well before our EDP presentation time slot to rehearse everything one last time. • We should all memorise key points to avoid going on tangents and off script.

## 3 Reflections

### 3.1 Week 1

### 3.1.1 Entry 1 (18/02)

What am I doing well?

- I took initiative alongside the team in raising the importance of clamp designs and wheel configurations early on in the project as it would influence decisions later on.

Furthermore, as a team we evaluated that I’m the most comfortable with the electronics and coding side of things, thus, I took the lead and initiative in running a preliminary test with the PixyCam. That is, colour detection.

What is our team doing well?

- There was very good engagement and enthusiasm in the first informal session as everybody contributed to the discussion and provided their own input. And everyone was on the same page of aiming for a HD in the course and project.

Why were the task(s) important?

- The wheel configuration task was crucial as it determines the chassis design and manoeuvrability. Therefore, getting this right early would mean future redesigns and issues will be mitigated.
- The clamp design is also central to the robot’s functions, as establishing the roadmap now gives the mechanical subgroup a concrete starting point and successfully addresses the criteria.

What could I have/can I do better?

- I should have documented the sketches with annotations and labels during the session rather than after it.
- I could have pushed myself and my probably subgroup members for some preliminary component role assignments rather than leaving it for the next session.
- I should have requested Bradman to construct a more formal sketch.

Is the progress in alignment with schedule?

- Yes it is, as we made the most out of week 1 by focusing on familiarisation and early preliminary conceptualisation, and no project deliverables were missed.

What have I learned? What do I need to learn?

- I learned the pros and cons of 3 wheel and 4 wheel configurations. I need to learn the code/torque specifications for the servo to validate the functioning of the claw. I communicated early on the importance of deciding wheel config as early as possible. Because it cascades into further mechanical development.

### 3.1.2 Entry 2 (20/02)

What am I doing well?

- I took ownership of setting up the PixyCam independently, troubleshot driver issues and resolved them, and I took initiative in setting up colour signature detection early through my self-directed problem solving and testing.

What is our team doing well?

- That we formalised roles early to give everyone clear direction, responsibilities and accountability going into the actual designing/build phase.

Why were the task(s) important?

- This task was vital as the PixyCam is the main sensing component; which determines whether the right waste is being sorted or not. Without it, the robot cannot fulfil its core purpose. Moreover, formalising roles prevents duplication of work and effort while also ensuring that all subsystems have their own dedicated team.

What could I have done better?

- I should have researched/watched a video of PixyCam setup prior to wasting ˜1 hour of my time on troubleshooting to save time. I could’ve documented the exact saturation for later testing and reproduction.

Is the progress in alignment with schedule?

- Yes, the roles are assigned early and the first preliminary sensor test are completed within Week 1. This is keeping us on track for further tests, the EDP presentation, and the overall design phase.

What have I learned? What do I need to learn?

- I learned how PixyMon’s colour connected components mode works and how saturation, lamp settings, and lighting affects the reliability of colour signature detection.
- I need to learn, how to read PixyCam’s output data via Arduino Uno’s serial communication to use in code and to integrate it with other subsystems later.
- I communicated the findings from the PixyCam setup to the team, reporting to the leader and confirming that the sensor is viable for ball detection under arena lighting.

### 3.1.3 Entry 3 (21/02)

What am I doing well?

- Me taking early ownership and of the mapping the system architecture with subsystems to components independently. And, producing a mindmap the whole team can use for clear reference going forward.

What is our team doing well?

- Everyone is progressing on their own tasks and assigned work simultaneously without needing unnecessary formal meetings

Why were the task(s) important?

- The task of mapping every component to a subsystem with a defined role will ensure that the whole team has a mutual understanding of the entire system before prototyping begins. Furthermore, it prevents future issues regarding components being overlooked or used for the wrong purpose. Especially during wiring and assembling the mechanical bits.

What could I have done better?

- I could have communicated with subgroup leaders better and set up a virtual meeting to discuss the component-subsystem mindmap for varied input into the making of it.

Is the progress in alignment with the schedule?

- Yes it is, as the system architecture is essentially fully mapped by the very end of Week 1, ensuring that all subgroups have a clear foundation heading into Week 2 and the project.

What have I learned? What do I need to nearn?

- I have learned basically the full list of components provided and how they interacted in between subsystems.
- I should now learn the exact Arduino pin assembly/assignment to operate sensors. Furthermore, I communicated the LucidSpark mindmap to the team for future reference so I have not only learned but in a way ”taught” some team members.

### 3.2 Week 2

### 3.2.1 Entry 4 (23/02)

What am I doing well?

- By taking ownership of PixyCam and troubleshooting independently and resolving the macOS compatibility issue without needing team support I think was something I did really well.
- Also, by contributing meaningfully to the sensor testing plan ahead of Week 3 physical testing, I set the team in a really good position.

What is our team doing well?

- The team formalised a clear workflow and deadline structure early, which sets a strong foundation for managing the increasing workload over coming weeks.

Why were the task(s) important?

- Selecting the 4 wheel configuration and claw clamp mechanism on this date was a pivotal decision because, it gave all subgroups a fixed design direction to work from and it prevents wasted effort on redundant work.

- Furthermore, establishing the workflow and deadline structure now also means the team is organised before the workload peaks rather than after.

What could I have done better?

- I could’ve come to this meeting with a more concrete sensor testing data to share, rather than just a plan. Having early results would have given the team more to work with when making design decisions.

Is the progress in alignment with schedule?

- Yes, because major design decisions were finalised in Week 2 which seems like a relatively normal week but in reality is crucial to get things done in this week. Workflow established, and prelab completed all within Week 2. Moreover, the team is on track heading into the first lab session.

What have I learned, and what do I need to learn?

- What I learned: how to diagnose and resolve PixyCam driver issues (minor thing), and moreover I learnt the value of locking in key design decisions early to unblock parallel workstreams. Additionally, in terms of technical knowledge I learned what each pin means on the sensor and how to integrate it with the Arduino.
- What I need to learn: how to integrate sensor outputs with Arduino motor control logic ahead of/during Week 3 testing. Additionally, I communicated the PixyCam compatibility findings to the team, the prelim sensor setup and simulations, and contributed to the discussion on ball collection mechanism selection.

### 3.2.2 Entry 5 (26/02)

What am I doing well?

- I am doing well in terms of leadership of my particular subgroup and across subgroups with other sub leaders, especially by taking initiative to test the servo physically on the Arduino rather than relying solely on simulation.
- I organised this with Franklin via a Teams call and we produced a critical finding about the 180 degree ROM limit that directly informs the gripper mechanism design and its constraints that we have to keep in mind.

What is our team as a whole doing well?

- Our decision to start the EDP presentation in Week 2 well ahead of the Week 5 deadline shows good time management by us, furthermore, continuing to track the progress on a Gantt chart is proving to be incredibly helpful.
- Moreover, dividing crazy eights by subsystem ensures that every area of the robot gets its own dedicated set of people to work on and ideate concepts.

Why were the task(s) important?

- The physical servo test was crucial in allowing our discovery of the 180◦ROM limit. Had this been found during the build phase it could have caused significant redesign delays in terms of code mapping to the servos (with inputs greater than 180◦on the IDE.)
- Further, scaffolding the problem statement and confirming concept generation tools early gave the team plenty of time to start and refine the EDP presentation properly.

What could I have done better?

- Franklin and I should have tested all of the metal gear servos rather than just one to confirm the ROM limit is consistent across all three servos in the kit. Furthermore, we could have also easily completed running the motor and planning to run it via the driver.

Is the progress in alignment with schedule?

- Yes, it is coming along smoothly and up to date as the servo testing is completed, problem statement scaffolded early, and concept generation tools confirmed all within Week 2, this is comfortably ahead of schedule.

What have I learned and what do I need to learn?

- A key thing I learned as mentioned across the reflection was that the metal gear servos have a maximum ROM of 180◦
, hence the gripper actuation must be designed and coded within this constraint. This not only showed our identification of limitations but how to grapple with them too.
- In terms of what I need to learn, I think I should read up on how to map specific angles for the servo to our own gripper’s positions such as fully open, partially open, and closed.
- Moreover, Franklin and I communicated the 180 degree ROM finding to the team so the mechanical subgroup can factor this into the physical gripper design whilst the programming subgroup can code within this constraint.

### 3.2.3 Entry 6 (27/02)

What am I doing well?

- One thing I did quite well was that I produced a thorough and well thought out Crazy Eights sheet, which covered 8 unique sensor layout and integration concepts with clear labelling and a sort of a ”logic structure” for each concept. I believe if I continue this attention to detail throughout the course, I will be rewarded.
- I further identified a preferred concept on my own in regards to my Crazy Eights (tiered sensing zones). And, I noted its strengths relative to the other concepts I drew, this shows analytical thinking beyond just simple sketching on my behalf. Additionally, most other team members did this sort of thinking too.

What is our team as a whole doing well?

- All team members managed to complete their Crazy Eights on time (well ahead of the formal deadline within late W2) and communicated their designs as images via Teams, this shows great accountability on behalf of every team member. And, the fact that everyone followed through on the agreed deadline structure meant that we were well on track for the EDP presentation in W5.

Why were the task(s) important?

- The Crazy Eights was necessary because it forced quick thinking and it prevents the team members from latching onto the first idea that seems like the ”best” one.
- Moreover, the fact that each member needed to cover a specific subsystem meant that our concept generation phase would be comprehensive and there would be no area of the robot design is overlooked. In addition, it is the most efficient way to complete this task too.
- Also, the mindmap and morph chart together gave the team a structured way to collate everyone’s own ideas into understandable and reasonable concepts for the EDP presentation ahead of Week 3 and 4.

What could I have done better?

- I think that I could’ve more formally evaluated each of the 8 concepts against design criteria rather than just identifying a favourite under timed conditions (perhaps an evaluation sheet), which would make the reasoning and my final concept selection more rigorous.
- I believe when I made concept 8 (the minimalist face plate) I dismissed it quickly and kind of just duplicated concept 3 due to the time limit. Perhaps it could have been worth going back and seeing whether enclosing components could modularity benefits during the build phase of ours project.

Is the progress in alignment with schedule?

- Yes, for sure, because everyone’s Crazy Eights were completed by the set deadline, the mindmap is being populated and on track to completion. The morph chart will be fully produced by start of week 3. All of these, are keeping the team well on track and even a bit ahead of schedule for concept finalisation and creating our EDP scripts in Week 3.

What have I learned and what do I need to learn?

- I believed that I learned the value of timed concept generation in forcing out quick and even unconventional solutions. This mitigates the outcome of ”just the most convenient and the best idea being produced.” And, I learned that the pan servo camera and tiered sensing zone concepts has the best efficacy for real world detection cases.

- I personally feel that I need to learn exactly how the tiered sensing zone logic would translate into actual Arduino code. This is of course for Week 5 and beyond but I would be interested in specifically learning how sensor zones would lead to different signals in the locomotion and retrieval systems.
- In terms of what I communicated, I sent our Teams channel a PDF of my sensor integration Crazy Eights. Thereby contributing to the team and everyone’s ideas too. All of which will feed into the final three concepts.

### 3.3 Week 3

### 3.3.1 Entry 7 (02/03)

What am I doing well?

- One good thing I am doing is actively contributing to the refining of the problem statement and bringing sensor integration knowledge into the group discussion. Putting us ahead of schedule. Furthermore, while I am leading on the technical side of things. I am following along with Jesse and Yusuf’s plan for the problem statement and contributing as a team player too.
- The fact that I completed sensor testing independently and producing a code with a working median filter solution for the sensors and bringing this info to the group.

What is our team doing well?

- The team came to the group meeting having all completed their Crazy Eights on time, which meant the session was productive rather than catching up on missed work
- That we sought feedback from both the mentor and lecturer. This proactively shows that our team is serious about hitting the mutually agreed upon HD criteria rather than just submitting something adequate and passing.

Why were the task(s) important?

- We thought that getting the problem statement right early was critical because it anchors the entire EDP presentation based on our reading of the rubric. Because, we figured that it not only is a requirement of the EDP but it actually ensures that we’re actually solving the right specific problem.
- Furthermore, sensor testing early on in Week 3 before compliance testing validated the sensor testing planning that I made in Week 2 and it also gave my subgroup and the whole team something to work with/understand going into the integration phase in W5.

What could I have done better?

- I think I really should have tested both IR sensors rather than just the one to confirm that there is consistency, since both will be used in the final design.

- I should’ve also started drafting concept sketches earlier rather than waiting until the problem statement is fully locked in, because I believe that some parallel progress is always good.

Is the progress in alignment with schedule?

- For sure, I would even say ahead of schedule. Because, I had the sensor testing completed, we all had our Crazy Eights reviewed, the mindmap on track to completion, and the problem statement drafted and presented to Wendy and Brielle all within Week 3.
- Our action item of three concept solutions are targeted by end of Week 3 which is on track to completion

What have I learned, and what do I need to learn?

- I learned that ultrasonic sensors produce messy inaccurate readings in cluttered environments that requires some sort of filtering in code. And, that the IR sensors used inverted logic where LOW signals detection rather than HIGH. Info gotten from Wendy’s technical lectures
- I strongly think I need to learn how to run both sensors simultaneously on the Arduino. I must consult the electrical subgroup for this.
- I communicated to my team, the sensor testing findings and the codes and the coding process via Teams. And, I contributed to the group problem statement as a team player in the editing process by giving my input.

### 3.3.2 Entry 8 05/03

What am I doing well?

- Taking ownership of the concept sketching and annotation responsibility, which is a direct contribution to the EDP presentation quality
- Contributing meaningfully to the concept synthesis discussion by drawing on sensor integration knowledge from the Crazy Eights session

What is our team as a whole doing well?

- The team effectively synthesised a large amount of ideation output across six individual Crazy Eights, a full mindmap, and a morph chart into three coherent base concepts in a single meeting
- Assigning clear ownership of next steps immediately after the meeting keeps momentum going without ambiguity

Why was/were the task(s) important?

- This meeting was the convergence point of all the divergent ideation done in Week 2 – without it the team would have a lot of ideas but no direction

- Locking in three base concepts this week gives enough time for sketching, Pugh Matrix scoring, and script writing before the Week 5 presentation

What could I have/can I do better?

- Could have come to this meeting with preliminary sketch concepts already drafted, which would have made the discussion more concrete and sped up the finalisation process

Is the progress in alignment with schedule?

- Yes – three base concepts defined, ownership assigned, and Pugh Matrix scheduled for start of Week 4, all on track for the Week 5 presentation deadline

What have I learned, what do I need to learn, and what have I taught/communicated?

- Learned: how to move from divergent ideation tools to a concrete shortlist through structured team discussion, and that the morph chart was the most useful reference point for comparing approaches across subsystems
- Need to learn: how to produce clear and informative annotated engineering sketches that communicate both the design intent and the sensor layout effectively
- Communicated: sensor integration preferences and constraints to the group during concept synthesis, directly influencing which sensor layouts made it into the three final concepts

### 3.3.3 Entry 9 (07/03)

What am I doing well?

- I strongly believe that me taking initiative as a subgroup leader to coordinate a meeting with the other subgroup leaders over the weekend to lock in the three final concept solutions ahead of schedule was something I did well.
- Also, starting the concept sketches early rather than leaving them to the last minute, was a good choice. Because, to make them good and make the annotations clear and accurate, I would need 2-3 days to refine it to a high quality.

What is our team doing well?

- The fact that all members are independently and keenly doing work and adding onto their EDP sections and scripts without needing constant nagging and coordination from Jesse is a really good thing. This is showing that the subgroup structure we and Brielle established in Week 2 is working really well.

Why were the task(s) important?

- Shortlisting and locking in the three final concept solutions, especially at this point of time is absolutely critical milestone for many reasons. First, it allows me to begin the sketching process, the Pugh Matrix, and the script writing. Because, they all depend on having confirmed concept solutions tto work from.

- Furthermore, starting the sketches early gives enough time and headroom for refinement and annotation, which ensures that the quality of the EDP presentation slides is high and presentable.

What could I have done better?

- I should’ve aimed to fully complete the tasks within the week by coordinating the meeting earlier, rather than carrying the annotation and sketching work into Week 4. Even thugh the deadline structure technically allows for it to be extended, it would have been better and given me more headroom.
- I could have documented the shortlisting discussion more formally via Teams, so that the reasoning behind each concept selection could be recorded more in detail for this design journa.

Is the progress in alignment with schedule?

- Yes, it is right up to schedule because we have three concept solutions shortlisted, the sketches started, and individual EDP script work is on track to completion. So, I’d say that everything is heading the right direction into Week 4 where the EDP presentation will be solidified and information will be cross checked and shared.

What have I learned and what do I need to learn?

- I have learned that shortlisting from a (really) large pool of ideas is much easier when we have structured concept generation tools like the morph chart as a reference. In my opinion it made trade offs between subsystem approaches much clearer to understand.
- I believe I need to learn how to produce annotated engineering sketches that are clear and well laid out so it can stand alone on a presentation slide without much talking from my side.
- I have communicated the final concept solutions shortlist and my EDPP script to the entire team via our unofficial channel on Instagram and also on Teams. This was very beneficial as I could get feedback from my team members on what I can improve on and maybe do better next time. As I firmly believe that as a sub leader and a team player I need to be humble and look for other opinions and input on my work. Rather than being tunnel visioned.

### 3.4 Week 4

### 3.4.1 Entry 10 (09/03)

What am I doing well?

- We completed all three concept sketches with full annotations just in time for the Monday meeting, demonstrating good time management and follow through on tasks carried over from Week 3

- The sketches were clear and detailed enough to anchor the team’s Pugh Matrix discussion, which shows the quality of the work was sufficient for its purpose

What is our team as a whole doing well?

- We all completed the Pugh Matrix collaboratively and reached a clear consensus on Concept 3, showing that the structured evaluation process worked well and that all members were engaged in the decision
- Everyoe came to the meeting with their EDP sections progressed enough to brief the team, which kept the session productive.

Why were the task(s) important?

- Completing the concept sketches was essential – without annotated visuals the Pugh Matrix discussion would have been abstract and harder to evaluate objectively
- The Pugh Matrix is a critical deliverable for the EDP presentation and formally justifies the selection of Concept 3, which is a key part of the concept generation section worth 40% of the presentation mark

What could I have done better?

- Ideally the sketches should have been fully completed in Week 3 rather than carried into Week 4, even though they were finished on time – tighter self imposed deadlines would reduce last minute pressure

Is the progress in alignment with schedule?

- Yes, becayse the concept sketches were completed, Pugh Matrix done, and final concept selected all in Week 4 with the presentation still a week away, leaving sufficient time for rehearsal and refinement

What have I learned and what do I need to learn?

- I learned that the Pugh Matrix is most effective when the whole team evaluates together rather than independently, as group discussion surfaces trade offs that individuals might miss
- I need to learn how to deliver the concept solutions section confidently within the 2 minute time limit without reading from notes, as the rubric caps marks at 60% for note reading
- I communicated completed concept sketches and annotations to the full team, which directly enabled the Pugh Matrix session and the final concept selection

### 3.4.2 Entry 11 (12/03)

What am I doing well?

- I personally, by arriving to the meeting with a fully written and timed script ready for review, did something well and up to team expectations as listed in our team contract. This meant that the session could focus on actually refining the scrip rather than writing new bits or inquiring me about missing sections
- I did not take the lead this session as I wanted to contribute as a team member, to the cohesion of the master script beyond just my own section. I reviewed the final script with Jesse leading the final review.

What is our team doing well?

- The fact that we produced a single cohesive master script with slide change directions and speaker cues shows that we were very well prepared. It showed that we have a high level of preparation ahead of the presentation.
- The team as a whole identified that Yizhuo and Bradman’s intro and conclusion needed extra support at the start of the meeting. Thus, we addressed this proactively rather than leaving it to last minute.

Why were the task(s)important?

- Having a master script with transitions makes sure that the presentation has a proper smooth delivery rather than six separate people reading their own sections without any cohesion. This is critical for the presentation component of the marking rubric worth 20% of the EDP mark
- The fact that we finalised slides now will leave the weekend solely for rehearsal. This mitigates the risk of last minute changes that could throw off our final performance.

What could I have done better?

- I should’ve begun rehearsing without notes immediately, because the rubric caps marks at 60% for reading from notes, so I had to memorise key points before Monday. This is non negotiable
- I could have prepared transitional sentences for my section handing over to the conclusion in advance rather than writing during the session which would’ve saved time
- I should have taken lead in some thing during the meeting, However, for this one I decided to solely be a ream player and contributor.

Is the progress in alignment with schedule?

- Yes, and things are looking good. Since we have the master script completed and slides finalised with 3 days remaining before our W5 Monday presentation. This has left us with more than enough time for independent and group rehearsals.

What have I learned and what do I need to learn?

- I have learned through this whole process that a presentation is really solid and strong when transitions between speakers are scripted rather than improvised. Furthermore, that everyone working towards trimming the script passively gives people info on other sections.
- I need to learn how to deliver the concept solutions section naturally from memory, without sounding robotic and staying within my time limit.
- In terms of communications, I simply presented my concept solutions script and slide structure to the team through OneNote.

## References

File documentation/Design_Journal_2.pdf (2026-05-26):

## Design Journal 2

### DESN1000 - Week 9

### UNSW zID: xxxxxxx

### Page Count: 73

## Contents

1 Design Process | 1
2 Teamwork | 38

3 Reflections | 58

## 1 Design Process

### 1.1 Week 5

### 1.1.1 Entry 1 (17/03)

With the EDP presentation behind us, the team’s focus now shifted to preparing for Compliance Testing (CT) on Week 7 Monday. On the 16th of March, we had a team meeting where Jesse outlined the priorities heading into Flexi Week. Then on the 17th, I posted a detailed roadmap on Microsoft Teams breaking down what we need to get done to be ready for compliance testing. See Figure 1 for the Teams post.

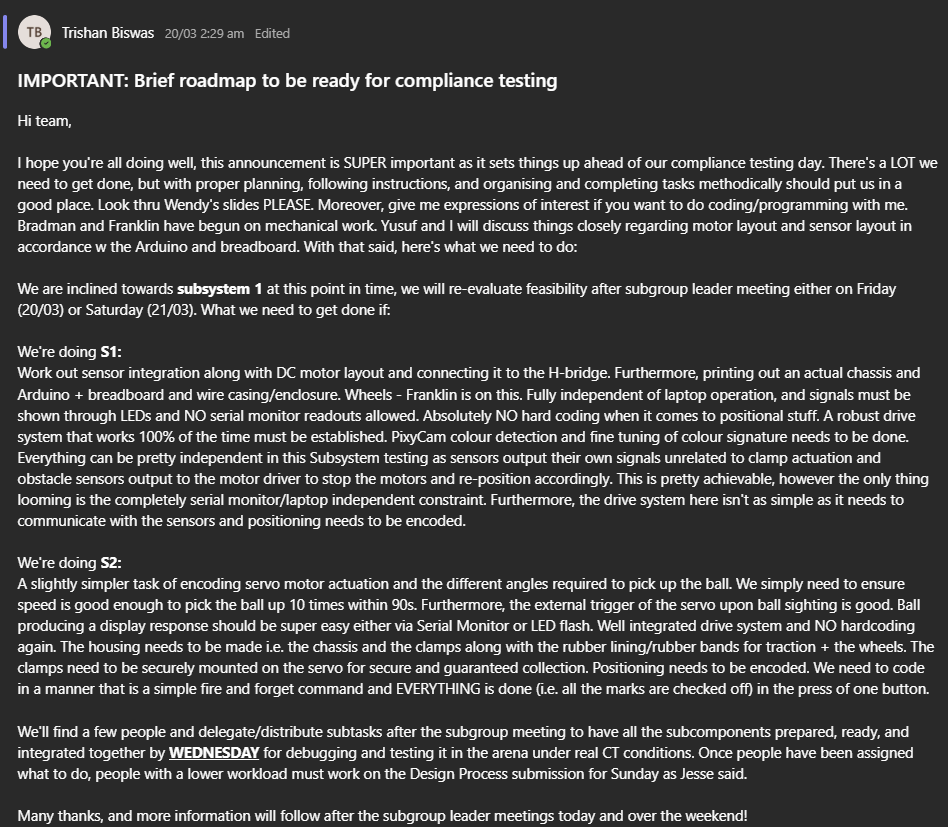
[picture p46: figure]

Figure 1: My compliance testing preparation roadmap posted on Teams. Posted by me

The main thing I did for this entry was evaluate which subsystem set (S1 or S2) would be most realistic for us to demonstrate at compliance testing. After the team meeting, I went home and made a flowchart comparing the two options against where we’re currently at, what resources we have, and the CT marking criteria. See Figure 2.

Leaning towards S1; confirm at subgroup leader meeting (19/03)

Figure 2: Flowchart evaluating S1 vs S2 feasibility for compliance testing. Made by me

I was leaning towards Subsystem 1 because I had already set up and tested the PixyCam’s colour signatures back in Weeks 2 and 3, so the colour detection side of things was largely sorted. On top of that, I had simulated the ultrasonic and IR sensors on TinkerCAD in Week 3, giving us a head start on obstacle detection too. Going with S2 would mean we’d need the chassis and clamp housing fully built, and the servo clamp mechanism reliable enough for 10 consecutive pickups in 90 seconds; which felt risky given where we were at. That said, the final call would be made at the subgroup leader meeting on the 19th.

In parallel, Franklin started working on the chassis design in Fusion 360 and Yusuf began looking into the power requirements and distribution for the electrical layout.

### 1.1.2 Entry 2 (19/03)

On the 19th of March, Jesse convened a subgroup leader meeting where we established and distributed the key tasks that need to be completed ahead of compliance testing. See Figure 3 for the task breakdown.

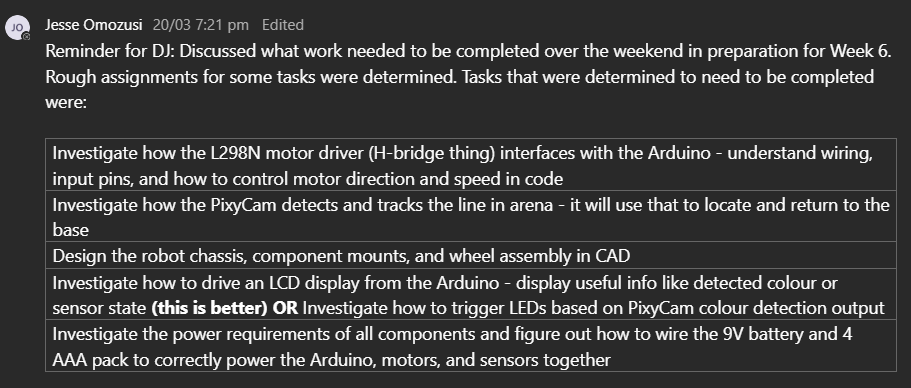
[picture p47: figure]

Figure 3: Task breakdown established at the subgroup leader meeting. Organised by Jesse

After the meeting, I got straight into my assigned tasks. The first thing I tackled was the Pixy-Cam. Through reading the Pixy2 documentation, I discovered that the Pixy2 cannot run line tracking and Colour Connected Components (CCC) mode simultaneously. This was a significant finding because it meant that for the “return to base” requirement in compliance testing, we could not rely on line following while also using the camera for colour detection. Instead, base colour recognition would be our approach for navigation back to the starting point.

I also looked into how the Pixy2 communicates with the Arduino Uno. The Pixy2 connects via the ICSP header using SPI protocol, which provides a two-way communication link. The Arduino can request block data (detected colour signatures, X-Y coordinates, signature size) from the Pixy2, and the Pixy2 receives 5V power through the same ICSP connection [1, 2]. Understanding this was important for planning how to integrate the camera data into the main control loop.

Next, I worked on the information display for compliance testing. Since S1 does not allow serial monitor output, I needed an alternative way to display the robot’s response to detected colours. I initially tried using LEDs but they were a hassle to get working properly with the limited remaining pins. So I switched to using a 16x2 LCD display (1602). At first I did not have an I2C backpack module, so I wired it directly to the Arduino using individual pin connections with a potentiometer for contrast adjustment. The connection layout was as follows:

Arduino Uno | 1602 LCD

10kΩ Pot

Pin 12 → RS

Pin | 11 → EN
Pin | 5 → D4
Pin | 4 → D5

Pin 3 → D6

Pin 2 → D7

5V → VDD, A+ GND → VSS, RW, K

Wiper → V0 (contrast)

Figure 4: LCD 1602 direct wiring layout to Arduino Uno (without I2C backpack). Made by me

I got the LCD displaying text successfully, but realised that this direct wiring method uses up a lot of Arduino pins (6 data/control pins) which we will need for motors and sensors later. So I ordered an I2C backpack for the LCD which would reduce the connection to just 2 pins (SDA and SCL), freeing up the others.

Additionally, during the subgroup leader meeting, we figured out that a separate 9V battery is required for the MKRVRS motor driver. This is because the DC motor stall current is higher than what the Arduino’s onboard power can supply, so an external source is needed to avoid voltage drops and potential damage. The power source for the servos and Arduino itself were still to be determined at this point.

### 1.1.3 Entry 3 (21/03)

On the 21st of March, I got the Pixy2 camera and LCD display working together with the Arduino. This was the first time we had a fully functional colour detection system that could identify a ball colour and display the appropriate action on screen without any laptop connection; exactly what compliance testing S1 requires.

I tested all three ball colours (red, green, blue) by placing the foam balls in front of the Pixy2 and checking whether the LCD correctly displayed the corresponding action. For red (signature 1), the LCD would display “Pick – RED (HDPE).” For green (signature 2), it displayed “Pick – GREEN (PET).” For blue (signature 3), it displayed “Pick – BLUE (PP).” And when a yellow ball was presented (or no target colour detected), the display showed an ignore/avoid response. See Figure 5 for the LCD displaying a detection result and Figure 6 for my Teams post communicating the results to the team.

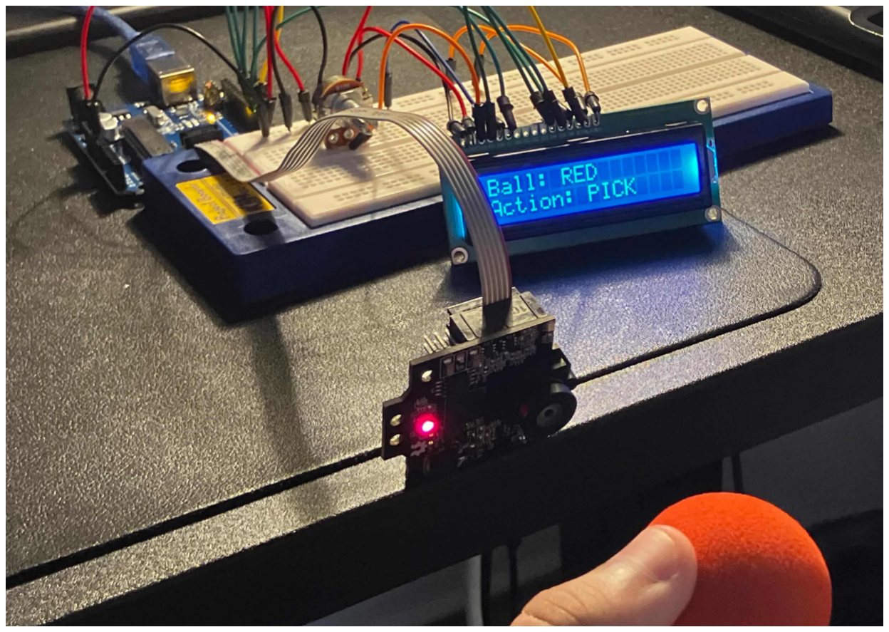
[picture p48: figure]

Figure 5: LCD displaying colour detection result from Pixy2 during testing. Done by me

Figure 6: Teams post communicating the Pixy2 + LCD test results to the team. Posted by me

The main challenge I ran into was learning how to print text on the LCD via C code on the Arduino IDE. The LiquidCrystal library handles this, but getting the cursor positioning right for multi-line output and clearing the display between detections took some trial and error. Once I got the hang of lcd.setCursor() and lcd.print(), it was smooth from there.

This was still using the direct-wired LCD without the I2C backpack, and through this test it became even more clear that we need the I2C module. The LCD alone is using 6 digital pins on the Arduino, and once we add the motor driver (4 pins), ultrasonic sensor (2 pins), IR sensor (1 pin), and servos (2 pins), we simply do not have enough pins left. The I2C backpack will reduce the LCD to just 2 pins (SDA and SCL), which frees up 4 pins for other components.

I also recorded a video of the full test and shared a thumbnail on Teams for the team to see. See Figure 7 for the video thumbnail.

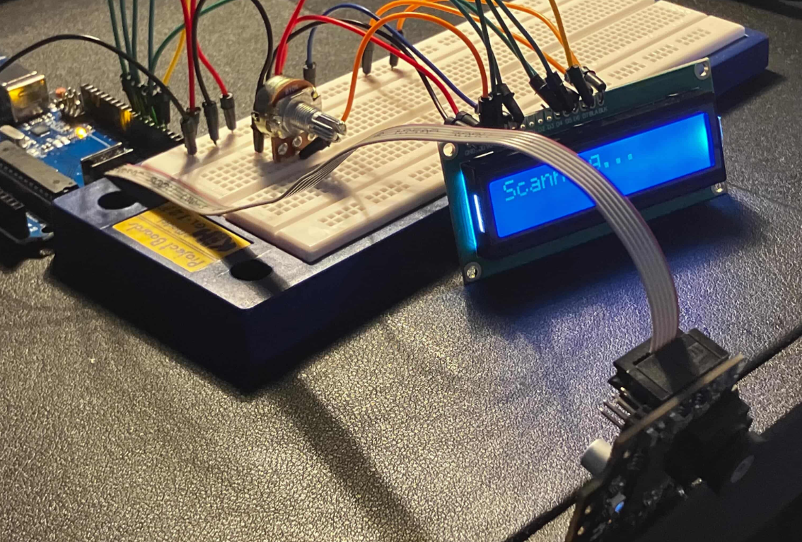
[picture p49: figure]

Figure 7: Thumbnail of the Pixy2 + LCD colour detection test video. Recorded by me

### 1.2 Week 6

### 1.2.1 Entry 4 (23/03)

On the 23rd of March, the whole team came into the ElecEng Building and Makerspace for our first proper build session from 1pm to 5pm. This was a big day as it was the first time we had all subgroups working physically on the robot at the same time.

Franklin and Bradman brought in the 3D printed wheels for testing and laser cut a test plywood chassis. They also 3D printed DC motor mounts which they screwed into the plywood to create a test chassis that we could use for integration testing. See Figure 8 for Franklin’s wheel dimension diagram and Figure 9 for the test chassis setup with motors mounted.

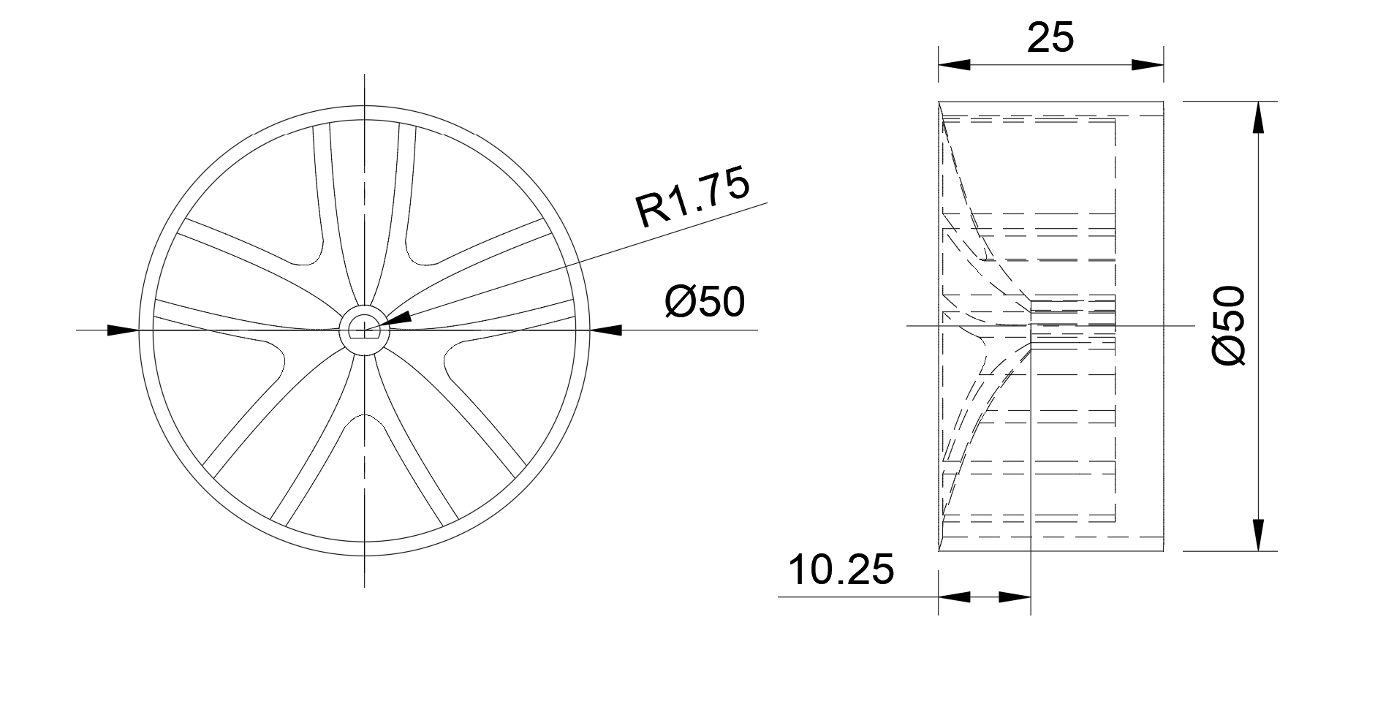
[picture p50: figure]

Figure 8: Wheel dimension diagram for the 3D printed wheels. Made by Franklin

Figure 9: Test plywood chassis with DC motors and wheels mounted for integration testing. Photo by me

Yusuf then worked with Bradman and Franklin to set up the MKRVRS motor driver pinouts with the DC motors. They wrote a basic test code to run both motors and it worked first try, which was a good sign. In parallel, Jesse trained the PixyCam colour signatures more thoroughly; he tweaked the block filtering, autoexposure, and camera brightness settings to get more reliable detection under the lab lighting conditions.

Once all of that was done, I took the test chassis to the lab and began my part of the work. First, I tested motor movement with PWM tuning across different movement directions; forward, backward, and turning. I experimented with different PWM values to find a speed that was controllable but not too slow. Then, I integrated an IR sensor with the motor control code to set up a basic obstacle detection proof of concept. The logic was straightforward:

- Motors run forward continuously at a set PWM
- When the IR sensor detects an obstacle (outputs a LOW signal), the motors stop
- When the obstacle is removed (signal goes back to HIGH), the motors resume forward movement

This was a simpler test than using the ultrasonic sensor with a distance threshold, but it served as a quick proof of concept that the motor driver and sensor could work together through the Arduino’s control logic. See Figure 10 for the video thumbnail of the obstacle detection test.

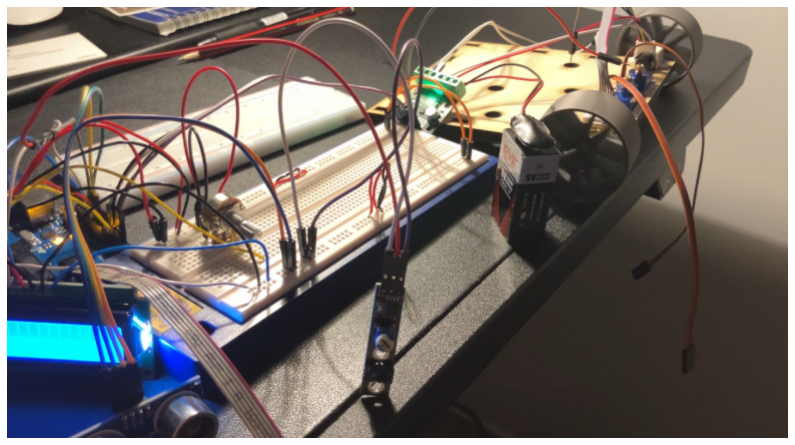
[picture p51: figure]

Figure 10: Thumbnail of the IR obstacle detection + motor stop/resume test. Recorded by me

### 1.2.2 Entry 5 (25/03)

On the 25th of March, the team came in again and this is when things really started coming together. Franklin and Bradman had 3D printed a proper PLA chassis plate which looked significantly better than the plywood test chassis from two days ago. They mounted the DC motors and rear caster wheel onto the chassis, and then we began mounting the MKRVRS motor driver on a dedicated precision mount on the chassis.

On the top plate, we mounted the Arduino UNO mounting points and the breadboard. Then, we attached the PixyCam and ultrasonic sensor front plate for our sensors. This assembly work was done by Franklin, Bradman, Jesse, and myself, with everyone present. Yusuf handled the I2C backpack soldering for the LCD and helped with the overall circuit pinouts. See Figure 11 for the assembled chassis with all components mounted.

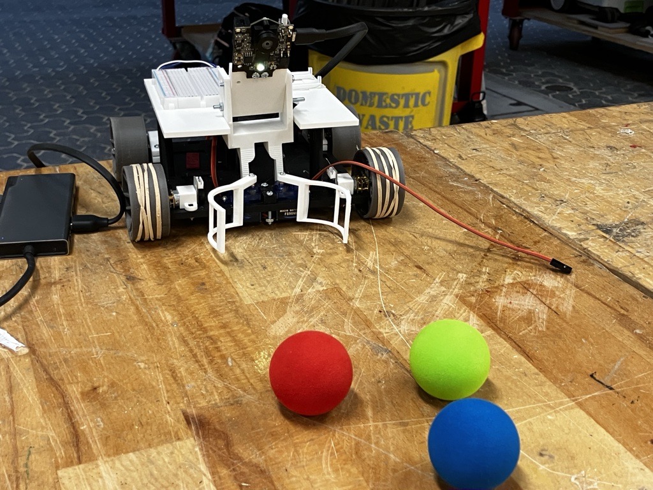
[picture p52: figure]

Figure 11: Assembled PLA chassis with motors, Arduino, breadboard, and sensor mounts. Photo by me

Once the PixyCam was mounted on the front plate, we quickly checked the field of view (FOV) and tuned the mounting angle so the camera could see both the ground level balls and the base colour plates. See Figure 12 for the PixyCam successfully detecting a colour signature at the mounted angle.

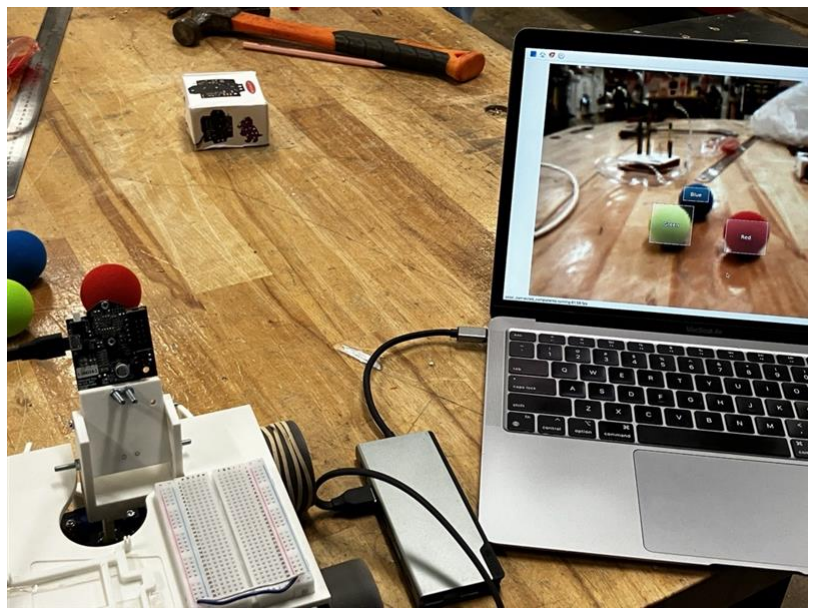
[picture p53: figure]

Figure 12: PixyCam mounted on the chassis and successfully detecting a colour signature. Photo by me

After the session, I took the robot home and rewrote the obstacle detection code to use the ultrasonic sensor instead of the IR sensor. I set a distance threshold of 20cm; when the ultrasonic reading drops below 20cm, the motors stop, and when the obstacle is cleared and the reading goes back above 20cm, the motors resume. This worked as expected and was a significant step up from the IR-based proof of concept because we now have actual distance data to work with for the compliance testing demo. See Figure 13 for the video thumbnail of this test.

Figure 13: Thumbnail of the ultrasonic obstacle detection test (20cm threshold). Recorded by me

### 1.2.3 Entry 6 (26/03)

On the 26th of March, we fully assembled and wired the robot for compliance testing. This was the critical debugging day we had targeted since the start of Week 5. The chassis was finalised, all components were wired to the Arduino, and we connected the power supplies: a 9V lithium polymer battery for the motors via the MKRVRS driver and a 9V battery via barrel jack to power the Arduino. See Figure 14 for the robot fully assembled and ready for compliance testing.

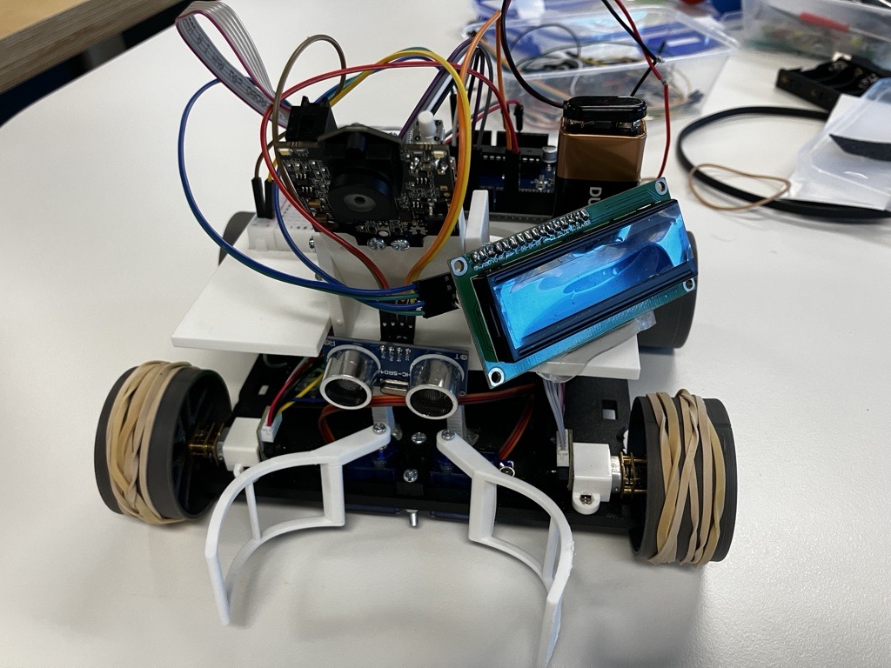
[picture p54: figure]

Figure 14: Robot fully assembled and wired for compliance testing. Photo by me

The overall circuit layout for the S1 compliance test configuration (without the IR clamp sensor and servos, as they are not needed for S1) is shown in Figure 15.

Arduino Uno9V barrel jack

Pixy2ICSP header

MKRVRSTC78H660 | HC-SR04Front central

1602 LCDI2C backpack

Motor L | 9V LiPo | Motor R

9V barrel

ICSP

Pin 2–5 | Pin 9, 10
A4, A5 | barrel

Common GND: Arduino – Motor driver – Sensors – LCD

Figure 15: S1 compliance testing circuit layout (IR clamp sensor and servos excluded). Made by me

Once the wiring was done, we tested the obstacle detection system on the floor. We set the robot moving forward at 100 PWM and placed our foot in front of it; it stopped, and resumed once the foot was removed. For the ultrasonic sensor, I carried over the median filter from Design Journal 1 to smooth out noisy readings. However, I then realised that in the actual compliance testing arena, multiple robots will be operating simultaneously, and their ultrasonic bursts could trigger false readings on our sensor. To address this, I devised a time jitter technique that randomises the trigger timing between readings so our sensor does not synchronise with other robots’ ultrasonic bursts [3]. See Figure 16 for the time jitter code.

void loop () {
// Read distance via median filter
int distance = medianFilter () ;

if ( distance > 0 && distance < OBSTACLE_THRESHOLD ) { stopMotors () ;
}

// Random delay breaks synchronisation with other // robots ’ ultrasonic sensors to prevent crosstalk delay ( random (50 , 150) ) ;
}

Figure 16: Time jitter technique to prevent ultrasonic crosstalk between robots. Coded by me

Next, we calibrated the rotation durations and PWM speeds for the different movement modes. Through trial and error on the arena floor, we settled on the following values:

// Movement PWM values
# define FORWARD_PWM | 80

# define BACKWARD_PWM | 60

# define TURN_PWM | 40

# define SLOW_APPROACH | 30

// Rotation calibration
# define TURN_180_MS | 1900 | // ms for 180 degree rotation

# define TURN_360_MS | 3800 | // ms for 360 degree rotation

Figure 17: Calibrated PWM speeds and rotation durations. Calibrated and coded by me

After the rest of the team left, Jesse and I stayed late until 9pm to test the base colour recognition system. Initially, we tried using raw RGB signature matching to identify the base colour, but it was inconsistent. As the robot moved around the arena, the lighting changed at different positions which caused the RGB values to shift. We tested it and it only worked 2 out of 20 times. We then switched to CCC training the base colour signatures directly in PixyMon; the same way we train the ball colours. After retraining, we fed the base signature data into the algorithm and it worked every single time. This confirmed that CCC-based base recognition is far more reliable than raw RGB matching.

With the base colour recognition sorted, I wrote the compliance testing algorithm that ties everything together. The flow is shown in Figure 18.

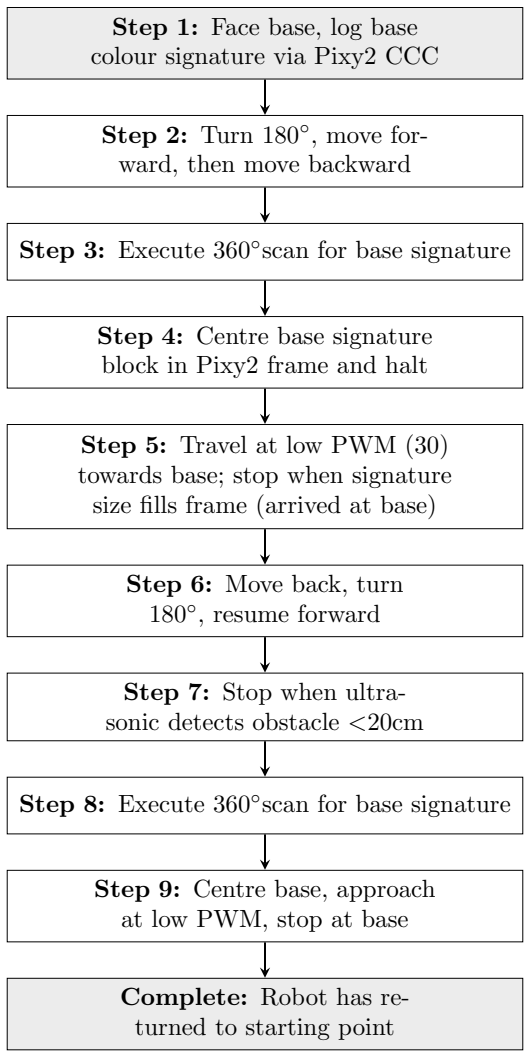
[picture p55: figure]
Step 1: Face base, log base colour signature via Pixy2 CCC; Step 2: Turn 180◦; , move for- ward, then move backward; Step 3: Execute 360◦; scan for base signature; Step 4: Centre base signature block in Pixy2 frame and halt; Step 5: Travel at low PWM (30) towards base; stop when signature size fills frame (arrived at base); Step 6: Move back, turn 180◦; , resume forward; Step 7: Stop when ultra- sonic detects obstacle <20cm; Step 8: Execute 360◦; Step 9: Centre base, approach at low PWM, stop at base; Complete: Robot has re- turned to starting point

Figure 18: S1 compliance testing algorithm for navigation and base return. Designed and coded by me

### 1.2.4 Entry 7 (28/03)

On Sunday the 28th of March, the team came in for a full dry run ahead of Monday’s compliance testing. This was our final chance to test the robot in the arena and iron out any remaining issues before the real thing.

We started by calibrating the ultrasonic threshold distance for obstacle detection. The previous 20cm threshold from Entry 5 was a starting point, but we needed to verify it worked under the actual arena conditions and CT marking criteria. We ran several tests where the robot would move forward and stop when approaching an obstacle, then resume once cleared. The obstacle detection was confirmed working at the calibrated threshold.

Next, we moved on to testing the turns. This is where we ran into a major issue. The 180◦ and 360◦
rotations were inconsistent every single time. After watching the robot attempt several turns, we identified the problem: the two rear wheels were dragging during rotation. Because both rear wheels are fixed and not powered, they resist the turning motion of the front differential drive, causing the robot to pivot inconsistently depending on minor surface variations

and battery voltage.

The solution was straightforward. We removed the two rear wheels and replaced them with a single rear caster wheel. A caster wheel can rotate freely in any direction, which means the robot can now essentially rotate on the spot without dragging resistance. Franklin and Bradman located the centrepoint on the rear of the chassis and bolted the caster wheel on securely. See Figure 19 for the robot standing on the single rear caster.

Figure 19: Robot standing on single rear caster wheel after removing the two fixed rear wheels. Photo by me

With the mechanical change done, I recalibrated all the turn durations and PWM values. The reduced friction from the caster wheel meant the robot turned faster and more consistently, so the PWM values needed to go 5–10 PWM lower to maintain control. The new calibrated values were:

// Recalibrated PWM values ( caster wheel )
# define FORWARD_PWM | 75 | // was 80

# define BACKWARD_PWM | 55 | // was 60

# define TURN_PWM | 35 | // was 40

# define SLOW_APPROACH | 25 | // was 30

// Recalibrated rotation durations
# define TURN_180_MS | 1750 // was 1900

# define TURN_360_MS | 3500 // was 3800

Figure 20: Recalibrated PWM speeds and rotation durations after caster wheel installation. Calibrated and coded by me

After the movement calibration, we tested the base colour recognition system. This revealed another issue. The PixyCam was detecting the base plate’s edge signature and stopping the scan immediately, then moving towards the edge rather than the centre of the base. This would cause the robot to approach the base at an angle and potentially miss it entirely.

The correct behaviour needed to be: the robot must do a side-to-side sweep until the base signature block is centred in the Pixy2’s frame, and only then halt the scan and begin the approach. Once approaching, the robot should stop when the signature size fills the frame, indicating it has arrived at the base. I modified the base recognition logic to include this centring step. See Figure 21 for the updated base approach algorithm.

Step 1: 360◦; scan for base signature; Step 2: Base signature de- tected? Record X-coordinate; Is signature centred?; No: Micro-adjust turn, recheck X-coordinate; Yes: Halt scan, begin approach at low PWM; Step 3: Approach base; monitor signature size; Signature fills frame?; Yes: Stop; robot at base; Yes

Figure 21: Updated base approach algorithm with signature centring logic. Designed and coded by me

We also tested the base colour logging system at startup. When the robot is first turned on and faces the base, the PixyCam logs the base colour signature so it knows what to look for during the return navigation. See Figure 22 for the LCD displaying the logged base colour on startup.


Figure 22: LCD displaying the base colour signature logged on startup. Photo by me

After all the fixes and recalibrations, we ran several trial runs in the arena to debug the full S1 algorithm end-to-end. See Figure 23 for one of the trial runs.

Figure 23: Trial run of the S1 algorithm in the arena during dry run debugging. Photo by me

By the end of the session, the mechanical issue with the rear wheels was resolved, the movement was recalibrated and consistent, and the base recognition logic had been updated. We were ready for compliance testing the next day.

### 1.3 Week 7

### 1.3.1 Entry 8 (30/03)

The 30th of March was compliance testing day. We arrived two hours early at James Kirby Makerspace, from 13:00, to run through everything before the actual CT session at 15:30. The plan was simple: electrical would handle any wiring issues, mechanical would deal with any chassis or mounting problems, and Franklin and I handled all the coding and algorithm testing. Jesse was there in an oversight and team leader capacity. Coming in early was essential because we needed to verify everything worked under the actual arena conditions, not just at home or in the lab.

The first thing I focused on during the pre-CT session was locking in the RGB colour detection cycle. The S1 compliance testing criteria requires the robot to detect a ball, display the correct response on the LCD, and cycle through the colour logic reliably. I ran the robot through repeated tests with red, green, and blue balls to make sure the PixyCam signatures were stable and the LCD output was consistent every time. A few parameter tweaks were needed to make sure no signature was being falsely triggered. See Figure 24 for the colour cycle detection running during pre-CT testing.


Figure 24: RGB colour cycle detection running during pre-CT testing. Photo by me

The second major thing I worked on was the base colour recognition sweep. The centreOnBase() function needed to reliably sweep, detect the base signature, centre it in the Pixy2 frame, and then approach. The logic works by reading the block X coordinate: if it is below 120 the robot nudges left; if it is above 196 the robot nudges right. Once the block sits within the 120 to 196 range, the robot stops adjusting and begins the slow approach, stopping when the signature size fills the frame. I wrote and refined this function and tested it repeatedly in the arena until it was consistently hitting the base without overshooting or drifting. See Figure 25 for the centreOnBase() function code.

void centreOnBase () {
lcdMsg ( " Centering ... " , sigName ( baseSig ) ) ;

for ( int attempts = 0; attempts < 40; attempts ++) { pixy . ccc . getBlocks () ;
for ( int i = 0; i < pixy . ccc . numBlocks ; i ++) {
if ( pixy . ccc . blocks [ i ]. m_signature == baseSig ) { int blockX = pixy . ccc . blocks [ i ]. m_x ;
if ( blockX >= 120 && blockX <= 196) {
// Centred enough
stopMotors () ;
return ;
} else if ( blockX < 120) { turnLeftSlow () ;
delay (60) ;
stopMotors () ;
delay (50) ;
} else {
turnRightSlow () ;
delay (60) ;
stopMotors () ;
delay (50) ;
}
}
}
delay (30) ;
}
stopMotors () ;
}

Figure 25: centreOnBase() function: nudges robot until base signature is centred in Pixy2 frame. Coded by me

The sweep-centre-approach sequence that centreOnBase() is part of was designed in Entry 7 and is shown in Figure 21. The full movement and navigation code summaries are shown in Figures 26 and 27.


Figure 26: Movement and navigation code algorithm summary (part 1). Made by me

Figure 27: Movement and navigation code algorithm summary (part 2). Made by me

Once both the colour detection cycle and the base navigation were confirmed working, we ran the full movement and navigation sequence end-to-end to verify the whole CT demo would flow without issues. See Figure 28 for the robot running through the full sequence during the pre-CT session.

Figure 28: Robot performing the full movement and navigation sequence during pre-CT testing. Photo by me

By the time we finished the pre-CT session we were confident every criteria point was covered. We headed into the actual compliance testing session at 15:30 with the robot fully calibrated and the algorithm locked.

### 1.3.2 Entry 9 (02/04)

On the 2nd of April, the team convened in the CompLabs from 12pm to 3pm for a Design Proposal progress check. The submission was due Sunday, so this was the opportunity to see what everyone had written and identify what needed fixing before the deadline.

I had been working on my assigned sections since Monday. For the Relevant Knowledge section, I wrote several subsections covering the PixyCam integration, ultrasonic sensor operation, and motor control logic. The goal of this section was to explain the technical principles behind each component choice and how they work together in our system. For example, the PixyCam subsection explained CCC mode, why we chose it over line tracking, how the ICSP header SPI connection works, and what block data (X coordinate, signature, area) the Arduino receives and acts on. The ultrasonic subsection explained the median filter and time jitter technique we developed, with the reasoning behind each. See Figure 29 for one of the code explanation snippets I wrote.


Figure 29: Snippet from Relevant Knowledge section explaining PixyCam and ultrasonic sensor integration. Written by me

I also made a TikZ circuit diagram for the Design Proposal documenting the full Arduino pinout and all component connections. This was important because the Design Proposal needed to show the marker that our electrical design is deliberate and well-documented, not just wires plugged in wherever they fit. The diagram shows the Pixy2 on the ICSP header, the MKRVRS motor driver on pins 2–5, the HC-SR04 on pins 9 and 10, the LCD via I2C on A4 and A5, and the two power rails (9V LiPo for motors, 9V barrel jack for Arduino) with common GND. See Figure 30 for the circuit diagram.


Figure 30: Arduino Uno circuit diagram with pinouts and component connections for the Design Proposal. Made by me

Additionally, Jesse and I brainstormed the final testing algorithm together. The CT demo only covered S1 (perception and navigation), but the final demonstration requires the full robot operation including ball pickup and sorting. We mapped out the high-level sequence: log base colour on startup, scan for target ball, navigate to it, collect it with the clamp, scan for the correct base, navigate to it, deposit the ball, and repeat for the R→G→B cycle. This was the first time we had the full end-to-end algorithm on paper, and having it as a flowchart gave us a clear reference for what the final testing code needed to implement. See Figure 31 for the final testing algorithm flowchart.

Figure 31: Final testing algorithm flowchart conceptualised with Jesse. Made by me

During the meeting, everyone presented their sections. Most were drafted but needed significant refinement; some sections were too vague and others were missing figures or technical justification. Jesse and I decided we would handle the bulk of the rewriting and editing on Saturday so that by Sunday’s submission the document would be ready, and the rest of the team could shift focus to final testing preparation. Jesse and I set up a shared Overleaf document so we could edit simultaneously without version conflicts. Yusuf had done the majority of the bibliography and sourcing work, which saved us a lot of time on the referencing side.

### 1.3.3 Entry 10 (04/04)

On Saturday the 4th of April, Jesse, Yusuf, and I met virtually on Microsoft Teams to edit and format the Design Proposal. The sessions were scattered throughout the day with check-ins between independent work periods, and the main meeting ran from 5pm to 7pm. Most of the actual editing happened asynchronously on the shared Overleaf document, which made it easy to see each other’s changes in real time without overwriting anything.

The main task was transferring Word drafts into LaTeX and making sure figures were embedded correctly. Several sections had been written in Word by team members who do not use LaTeX, so I handled the conversion: fixing formatting, adding \noindent and paragraph spacing, and making sure any tables or lists were properly structured. Jesse rewrote and tightened the weaker sections on his end while I focused on figure creation and layout. I also made sure the Gantt chart reflected our actual current progress rather than the original plan, since several tasks had shifted in timing after CT.

For figures, I created the TikZ block diagram for the system architecture (based on Jesse’s sketch), formatted Franklin’s wall-following diagram, and embedded the bibliography page. Having consistent TikZ figures throughout the document made it look more cohesive than a mix of screenshots and hand-drawn images. See Figure 32 for the wall-following figure diagram, Figure 33 for the updated Gantt chart, Figure 34 for the system block diagram, and Figure 35 for the bibliography.


Figure 32: Wall-following figure diagram for the Design Proposal. Diagram by Franklin


Figure 33: Gantt chart for the Design Proposal showing project timeline and progress. Made by Jesse


Figure 34: System block diagram for the Design Proposal. Made by Jesse

Figure 35: Bibliography compilation for the Design Proposal. Done by me and Yusuf

Yusuf handled the bibliography formatting in BibTeX, and we cross-checked citations against the sources to make sure everything was accurately attributed. By Sunday morning the document was fully formatted and submission-ready. We ran a final pass for spelling, broken references, and figure numbering before submitting.

### 1.4 Week 8

### 1.4.1 Entry 11 (06/04)

On the 6th of April, the full team met in Room 412 of the Main Library from 2pm to 3pm. This was a short meeting to do a progress check and read through the final testing notification together before the push towards final demonstration day.

We read through the Final Testing Specification as a team and made notes on the marking criteria. I made a quick block chart evaluating the requirements and what we need to hit for an HD. See Figure 1.4.1 for my evaluation.
We established action items to complete by Thursday’s meeting (9th April). I ordered a replacement LCD for $5 and tested it with a basic HelloWorld print. See Figure 36.

Figure 36: Replacement LCD tested with HelloWorld print. Photo by me

Franklin also made a diagram showing where the LCD would mount on a skeleton structure on top of the robot body. See Figure 37.


Figure 37: LCD mount placement diagram for the robot. Made by Franklin

We also determined the optimal PixyCam angle and height: 10cm from the top of the Pixy, angled at 20–30 degrees downwards for best ball detection. Franklin and Bradman began figuring out a 3D printed mould solution with silicone curing for wheel covers (instead of blu tac). Roles were assigned: Franklin to design mechanical components (LCD mount, upper level with perfboard and Arduino, bottom level with motor driver and servo batteries), Yusuf to solder everything directly without header pins, Bradman to assist Franklin, and Jesse to oversee and assist where needed.

### 1.4.2 Entry 12 (09/04)

On the 9th of April, the team met to follow up on the action items from Monday. We confirmed the optimal PixyCam mounting angle and tested the positioning. Franklin and Bradman 3D printed the wheel mould for silicone curing and printed the LCD mount; we were waiting for the next print cycle.

I completed the final testing code (final testing.ino) which implements the full ball pickup and sorting algorithm for HD target. The code follows a strict R→G→B cycle and handles all 11 steps of the operation. See Figure 38 for the configuration section and Figure 39 for the main run sequence.

namespace Config {
// Motor pins
constexpr int DIR_A = 2;
constexpr int PWM_A = 3;
constexpr int DIR_B = 4;
constexpr int PWM_B = 5;

// Speeds ( PWM 0 -255)
constexpr int NORMAL_SPEED = 80; constexpr int APPROACH_SPEED = 65; constexpr int CRAWL_SPEED = 40; constexpr int TURN_SPEED = 80;

// Timing
constexpr int TURN_180_MS = 1400;

// Thresholds
constexpr int BALL_AREA_THRESHOLD = 8000; constexpr int BASE_AREA_THRESHOLD = 15000; constexpr int OBSTACLE_DISTANCE_CM = 20;

// Ball signatures ( Pixy2 CCC )
constexpr int SIG_RED = 1;
constexpr int SIG_GREEN = 2; constexpr int SIG_BLUE = 3;

// Base signatures
constexpr int SIG_ORANGE = 4; constexpr int SIG_YELLOW = 5; constexpr int SIG_PINK = 6; constexpr int SIG_PURPLE = 7;
}

Figure 38: Configuration namespace from final testing.ino: pin definitions, speeds, thresholds, signatures. Coded by me

void runSequence () {
step1_logBaseAndOrient () ; // Log base colour , turn 180

while ( true ) {
step2_scanForTargetBall () ; // 360 scan for R / G / B
step3_navigateToBall () ; | // Centre and approach
step4_finePosition () ; | // IR fine positioning
step5_collectBall () ; | // Close clamp if correct
step6_verifyCollection () ; | // Confirm ball secured
step7_scanForBase () ; | // 360 scan for base
step8_navigateToBase () ; | // Centre and approach base
step9_approachBase () ; | // Ultrasonic precision
step10_depositBall () ; | // Open clamp , back away

if ( step11_checkStatus () ) break ;
// Advance : R - >G - > B cycle
}
lcdShow ( " Mission " , " Complete ! " ) ;
}

Figure 39: Main run sequence: 11-step cycle for ball collection and base deposit. Coded by me

The meeting also established the Week 9 timeline and deadlines:

Mon 14 Apr

Programming:
code mostly done

Mechanical: chassis CAD

Electrical: circuit diagram

Tue-Wed 15-16

3D print robot

Assemble chassis & circuitry

Code deadline

Thu 17 Apr

Train Pixy2

Practice runs

Troubleshoot

Fri-Sun 18-20

Test & troubleshoot

Paint finish

Final checks

Figure 40: Week 9 timeline and deadlines established at the meeting. Made by me

### 1.5 Week 9

### 1.5.1 Entry 13 (13/04)

On the 13th of April, the team met in Room 412 of the Main Library. This was later than planned in the Week 9 timeline; we should have been better with time management. The meeting focused on briefing everyone on assembly and code before the build.

I presented the overall algorithm to the team in detail, walking through each step and explaining how the final testing.ino draft code implements it. The 11-step sequence (log base, scan for ball, navigate, collect, scan for base, deposit, repeat) was now clear to everyone. Yusuf explained how he would solder all electronic components to the perfboard. Franklin showed the CAD models he had sent for printing: the clamps, base plate, top plate, LCD mount, and a casing that covers the inner skeleton to make the robot look like Wall-E.

After the briefing, the three subgroup leaders (Jesse, Franklin, Yusuf) brainstormed to ensure everything was in order: pinouts routing through the LCD mount to the Arduino shield, servo bracket placement avoiding conflict with ultrasonic and IR sensor layout, and general wire management.

We waited for the print jobs to complete. Once ready, Franklin and Yusuf assembled the chassis and placed components on their precision mounts: motor driver, PixyCam, IR sensor, ultrasonic, Arduino board, perfboard, and battery casings. I mounted the servos onto the bracket. See Figures 41, 42, and 43 for the assembly progress.


Figure 41: Assembled robot chassis without wiring. Photo by Yusuf, built by me, Franklin, and Yusuf

Figure 42: Servo motors mounted on bracket. Photo by me

Figure 43: Top level of inner skeleton with LCD mount, Arduino shield, and perfboard. Photo by me

The mechanical assembly was done by the end of the session. One key coding decision I made for the final testing algorithm was the bus isolation technique for the ultrasonic sensor. The HC-SR04 uses digital GPIO pins for trigger and echo, but the problem is that when the I2C bus (used by the LCD) and the SPI bus (used by the Pixy2) are both active, the electrical noise on the shared lines can interfere with the ultrasonic timing measurements. Even a few microseconds of corruption in the echo pulse duration translates to several centimetres of error in the distance reading. To prevent this, I wrote two functions that shut down the I2C and SPI buses before taking an ultrasonic reading and then restore them afterwards. The LCD backlight and display are also turned off during the measurement to eliminate any I2C traffic. See Figure 44 for the bus isolation code.

// Bus isolation for ultrasonic precision
void isolateBusesForUltrasonic () {
lcd . noBacklight () ;
lcd . noDisplay () ;
Wire . end () ; | // Shut down I2C
SPI . end () ; | // Shut down SPI
delay (100) ;
pinMode ( ECHO_PIN , INPUT ) ; pinMode ( TRIG_PIN , OUTPUT ) ;
}

void restoreBusesAfterUltrasonic () { Wire . begin () ;
lcd . init () ;
lcd . backlight () ;
pixy . init () ;
delay (200) ;
}

Figure 44: Bus isolation technique: shuts down I2C and SPI during ultrasonic readings to prevent interference. Coded by me

### 1.5.2 Entry 14 (15/04)

On the 15th of April, Yusuf and I went to the Elec Makerspace from 2pm to 5pm to continue the electrical connections. Franklin assisted initially with remaining mechanical fitting before handing over to us. Wiring was not yet fully complete at the end of this session; some connections remained to be finished at the next build day before a full powered test could be run.

The first connections we made were the clamp servos to the 4xAAA LiPo battery pack. Servos run on a separate supply from the Arduino and motor driver to stop PWM switching current from causing voltage dips on the Arduino rail, which can trigger resets mid-run. Critically, we tied the servo battery GND to the Arduino GND. Without this shared reference, the PWM signal from the Arduino has no common voltage to switch against and the servos either jitter continuously or do not move at all [4]. We then soldered the MKRVRS motor driver pinouts to the Arduino, testing each with the multimeter continuity beep test before powering anything: DIR A to pin 2, PWM A to pin 3, DIR B to pin 4, PWM B to pin 5. See Figure 45 for the motor driver soldering.


Figure 45: Motor driver pinouts soldered to Arduino with ultrasonic and IR common power/GND rail. Photo by me

Wiring the LCD to the perfboard revealed a fault: the VDD pin on the I2C backpack was not conducting. We identified this with the multimeter and desoldered that pin, switching to the secondary VDD pad. We also created a dedicated power rail and GND bus on the perfboard for the HC-SR04 and FC-51 IR sensor so both sensors share a single clean rail rather than individual wires back to the Arduino headers. See Figures 46 and 47 for the soldering progress.


Figure 46: Perfboard and shield with wires soldered. Photo by me

Figure 47: Wire routing through chassis holes; servo and motor driver wires soldered cleanly under chassis. Photo by Yusuf

### 1.5.3 Entry 15 (17/04)

On the 17th of April, the team met in the Elec Makerspace from 11am to 2pm. This was the final build session before the demonstration. Franklin, Bradman, and Yizhuo focused on the risk assessment and final report planning while Jesse trained the Pixy2 colour signatures for the new chassis configuration. Yusuf helped fix and tune the remaining electronics, and I handled the remaining code refinements and individual component testing.

The first priority was finishing the wiring connections left over from the 15th. Once those were done, I tested each component individually before combining them. The two sensors most at risk of interference due to their tight physical placement were the HC-SR04 ultrasonic and the FC-51 IR sensor, so these were tested first. The ultrasonic was confirmed working with the median filter and time jitter technique producing stable readings with no false triggers. The IR sensor was calibrated specifically to detect a ball sitting inside the clamp enclosure; since the sensor is enclosed, the detection threshold needed to be set for a very short range. Both sensors performed well in isolation.

The servo clamp was then tested for open and close angles. When the clamp was commanded to close, there was an initial jitter and a small jump before it settled into the closing motion. I debugged this and identified the cause: the solder joint connecting the servo to the battery negative terminal was not making proper contact, meaning the common GND connection was intermittent. This meant the servo’s reference voltage was floating, which caused the brief erratic movement before the joint made momentary contact and the servo responded normally. Yusuf reflowed the solder joint, and after that the servo opened and closed cleanly with no jitter.

Once all individual components were confirmed working, we connected everything together as per the full system configuration. The complete wiring follows the block diagram from the Design Proposal with the addition of the LCD on the I2C bus [5]. See Figure 48 for the full system

connectivity diagram.; Arduino Uno; 9V barrel jack Central controller; ICSP; Pin 2; Pin 3; Pin 4; Pin 5; Pin 6; Pin 7; Pin 9; Pin 10; Pin 11; GND; Pixy2 ICSP header – Sigs 1–7; MKRVRS TC78H660; DIR A ← Pin 2 PWM A ← Pin 3 DIR B ← Pin 4 PWM B ← Pin 5 VM ← 9V battery GND ← com- mon rail; Motor L; Motor R; 9V battery (motors); HC-SR04 Front central TRIG / ECHO; IR Clamp Sensor LOW on detection Pin 11; 2× Servo Motors; Sig1 ← Pin 6 Sig2 ← Pin 7 VCC ← 4×AAA LiPo; 4×AAA LiPo (servos); 1602 LCD I2C backpack SDA/SCL ← A4/A5; 9V battery (Arduino)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

Figure 48: Full system connectivity diagram for final testing configuration, including LCD on I2C bus (A4/A5). Made by me

With the full system wired up, I tested the sections of code that could be verified at this stage. The key function to confirm was the fine positioning loop in step4 finePosition(), which uses the IR sensor’s ballInClamp() reading to stop the robot as soon as the ball enters the clamp enclosure. This works by treating the IR output pin going LOW as a ball-present signal, then stopping all motor movement and exiting the loop. See Figure 49 for the step4 finePosition() code.

void step4_finePosition () {
lcdShow ( " Step ␣ 4: " , " Fine ␣ positioning " ) ;

while (! ballInClamp () ) {
int blockX = getBlockX ( targetBallSig ) ;

if ( blockX < Config :: FRAME_CENTRE_MIN ) { motorTurnLeft ( Config :: CRAWL_SPEED ) ;
delay (30) ;
motorStop () ;
} else if ( blockX > Config :: FRAME_CENTRE_MAX ) { motorTurnRight ( Config :: CRAWL_SPEED ) ;
delay (30) ;
motorStop () ;
} else {
motorForward ( Config :: CRAWL_SPEED ) ; delay (50) ;
motorStop () ;
}
delay (30) ;
}
motorStop () ;
}

Figure 49: step4 finePosition(): IR-guided fine positioning loop; crawls forward until ball triggers the clamp IR sensor. Coded by me

I also confirmed the two-phase base approach in step9 approachBase(), which first uses the Pixy2 block area to get within range, then isolates the I2C and SPI buses and switches to ultrasonic precision approach: slowing at 15cm and stopping at 5cm. See Figure 50 for the approach code.

void step9_approachBase () {
lcdShow ( " Step ␣ 9: " , " Approach ␣ base " ) ;

// Phase 1: Pixy area - guided approach
while ( getBlockArea ( baseSig ) < Config :: BASE_AREA_THRESHOLD * 1.5) { motorForward ( Config :: APPROACH_SPEED ) ;
delay (50) ; motorStop () ; delay (30) ;
}

// Isolate I2C / SPI for clean ultrasonic readings isolateBusesForUltrasonic () ;

// Phase 2: Slow down at 15 cm
long dist = ultrasonicMedian () ;
while ( dist > Config :: APPROACH_SLOW_CM || dist == 0) { motorForward ( Config :: APPROACH_SPEED ) ;
delay (50) ; motorStop () ; delay (30) ;
dist = ultrasonicMedian () ;
}
motorStop () ; delay (300) ;

// Phase 3: Crawl to 5 cm
while ( dist > Config :: APPROACH_STOP_CM || dist == 0) { motorForward ( Config :: CRAWL_SPEED ) ;
delay (30) ; motorStop () ; delay (30) ;
dist = ultrasonicMedian () ;
}
motorStop () ;
restoreBusesAfterUltrasonic () ;
}

Figure 50: step9 approachBase(): two-phase precision base approach using Pixy2 area then ultrasonic with bus isolation. Coded by me

By the end of the session all individual components were verified, the servo jitter fault was found and fixed, and the fully integrated system was wired and running. Jesse had completed the Pixy2 signature training for all ball and base colours on the new chassis. The robot is ready for full end-to-end testing.

## 2 Teamwork

### 2.1 Week 5

### 2.1.1 Entry 1 (17/03)

On the 16th of March, our team held a meeting to discuss the plan heading into Flexi Week and compliance testing preparation. Jesse communicated the key priorities via Teams on the 17th, and I followed up with my own detailed roadmap announcement shortly after. The subgroups are communicating well with the overall leader, and Jesse is tracking progress on the team Gantt chart.

Time | 16/03, 14:00 – 15:30
Location | Microsoft Teams (Online)
Attendance | All members were present.

Agenda | • Discuss compliance testing preparation and what needs to be done • Everyone must read the CT specification and rubric be-fore Thursday’s meeting • Collect availability for Flexi Week build days at UNSW • Franklin and Trishan to report on current robot progress and remaining work
Meeting Summary | • Jesse outlined the compliance testing timeline and key priorities for the team • We established that the robot needs to be ready for debugging by 26th March • Trishan posted a detailed roadmap on Teams breaking down the deliverables for both S1 and S2 • Franklin reported that chassis CAD work has begun on Fusion 360 • Yusuf began investigating power requirements and dis-tribution for the electrical layout • The team agreed to evaluate S1 vs S2 feasibility at the subgroup leader meeting on 19th March
Decisions Made | • Robot must be hardware-built and basic code working by 26th March for debugging • Subsystem choice (S1 or S2) to be confirmed after sub-group leader meeting on 19/03 • All members must reply with Flexi Week availability before Thursday’s meeting • Jesse tracking overall progress on the team Gantt chart

Action Items
- Everyone must read the CT specification and rubric before next meeting
- Franklin and Trishan to provide a progress update on what has been completed and what remains
- Trishan to evaluate S1 vs S2 feasibility and present findings at subgroup leader meeting
- Franklin to continue chassis design on Fusion 360
- Yusuf to continue investigating power distribution requirements
- All members to reply with Flexi Week availability

### 2.1.2 Entry 2 (19/03)

Jesse called a subgroup leader meeting on Teams to establish and assign the key tasks for compliance testing. The meeting was focused and productive; we came out with clear ownership of every deliverable.

Time | 19/03, 17:00 – 18:00
Location | Microsoft Teams (Online)
Attendance | Jesse, Trishan, Franklin, Yusuf (subgroup leaders)
Agenda | • Establish and distribute tasks for compliance testing preparation • Discuss power requirements for motor driver and servos • Confirm subsystem choice direction based on Trishan’s S1 vs S2 evaluation

Meeting Summary
- Jesse outlined the five key tasks and we assigned ownership as follows:
- Task 1 (Power distribution and wiring layout): Yusuf and Yizhuo
- Task 2 (Sensor integration and CT code): Trishan and Jesse
- Task 3 (Chassis build and mechanical assembly): Franklin and Bradman
- Task 4 (PixyCam and information display): Trishan
- Task 5 (Motor driver setup and testing): Yusuf and Trishan
- We identified that a separate 9V battery is needed for the MKRVRS motor driver due to the DC motor stall current exceeding the Arduino’s power output
- Power sources for servos and the Arduino itself are still TBD
Decisions Made | • Tasks distributed across subgroup leaders as listed above • Separate 9V battery confirmed for motor driver; servo and Arduino power TBD • Team leaning towards S1 for compliance testing based on current progress
Action Items | • Trishan to work on PixyCam integration, LCD display setup, and research Pixy2 SPI communication • Yusuf and Yizhuo to map out full power distribution and wiring layout • Franklin and Bradman to continue chassis build and be-gin mechanical assembly • Jesse and Trishan to begin writing CT demonstration code • Yusuf and Trishan to set up and test the MKRVRS mo-tor driver with DC motors

### 2.1.3 Entry 3 (21/03)

Time | 19/03 – 21/03
Location | Independent work / Microsoft Teams
Attendance | All members contributing independently
Agenda | • Each member progressing on their assigned compliance testing tasks from the subgroup leader meeting • Updates communicated via Teams

Meeting Summary
- Trishan completed the Pixy2 + LCD colour detection test for all three ball colours (red, green, blue) and communicated results on Teams with video evidence
- Franklin designed and 3D printed prototype wheels, tested them and found the axle hole was too large; began a CAD redesign with Bradman. Also identified that wheel width was too large and adjusted accordingly
- Yusuf figured out the MKRVRS motor driver pinout setup and set up an unsoldered configuration to test before committing to soldering
- Jesse researched how to train PixyCam CCC colour signatures more effectively, including tweaking settings like overexposure for better detection reliability
Decisions Made | • Colour detection and LCD display confirmed as working for S1 compliance testing • Wheel redesign needed before next print; axle hole and width to be corrected • Motor driver pinout confirmed; soldering to follow once verified
Action Items | • Trishan to set up I2C backpack for the LCD once it arrives to free up Arduino pins • Franklin and Bradman to reprint corrected wheels • Yusuf to solder motor driver connections once testing is confirmed • Jesse to share PixyCam training findings with Trishan for integration

### 2.2 Week 6
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

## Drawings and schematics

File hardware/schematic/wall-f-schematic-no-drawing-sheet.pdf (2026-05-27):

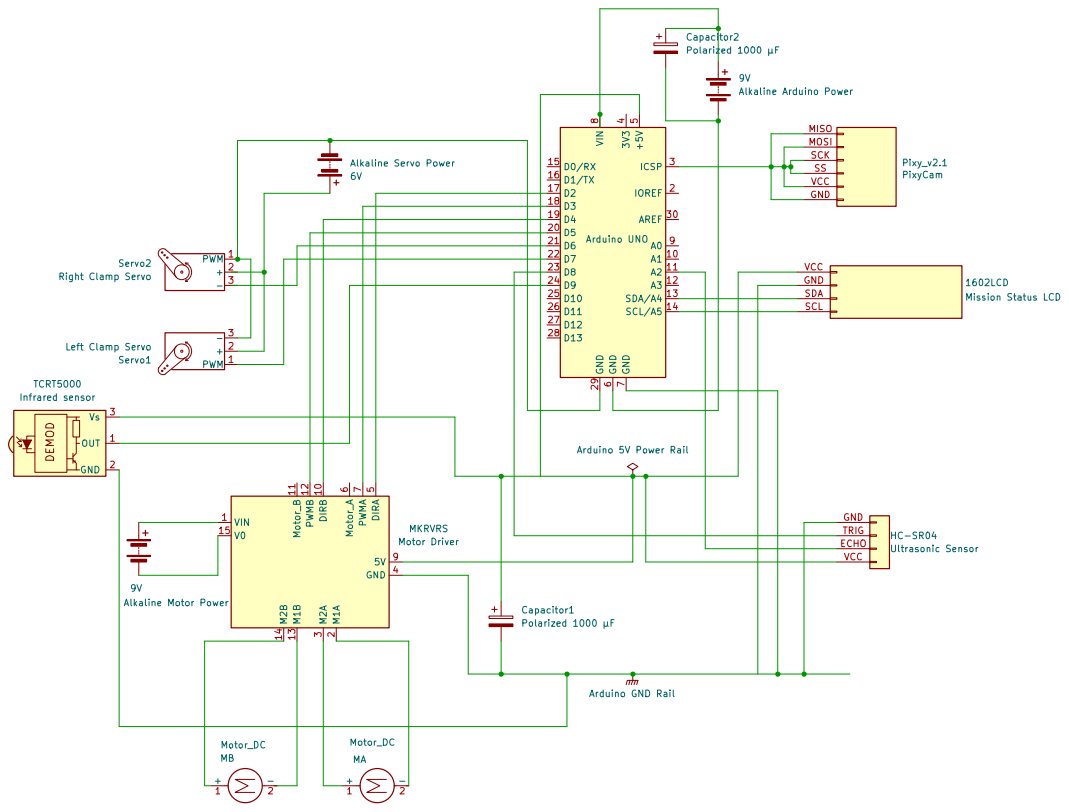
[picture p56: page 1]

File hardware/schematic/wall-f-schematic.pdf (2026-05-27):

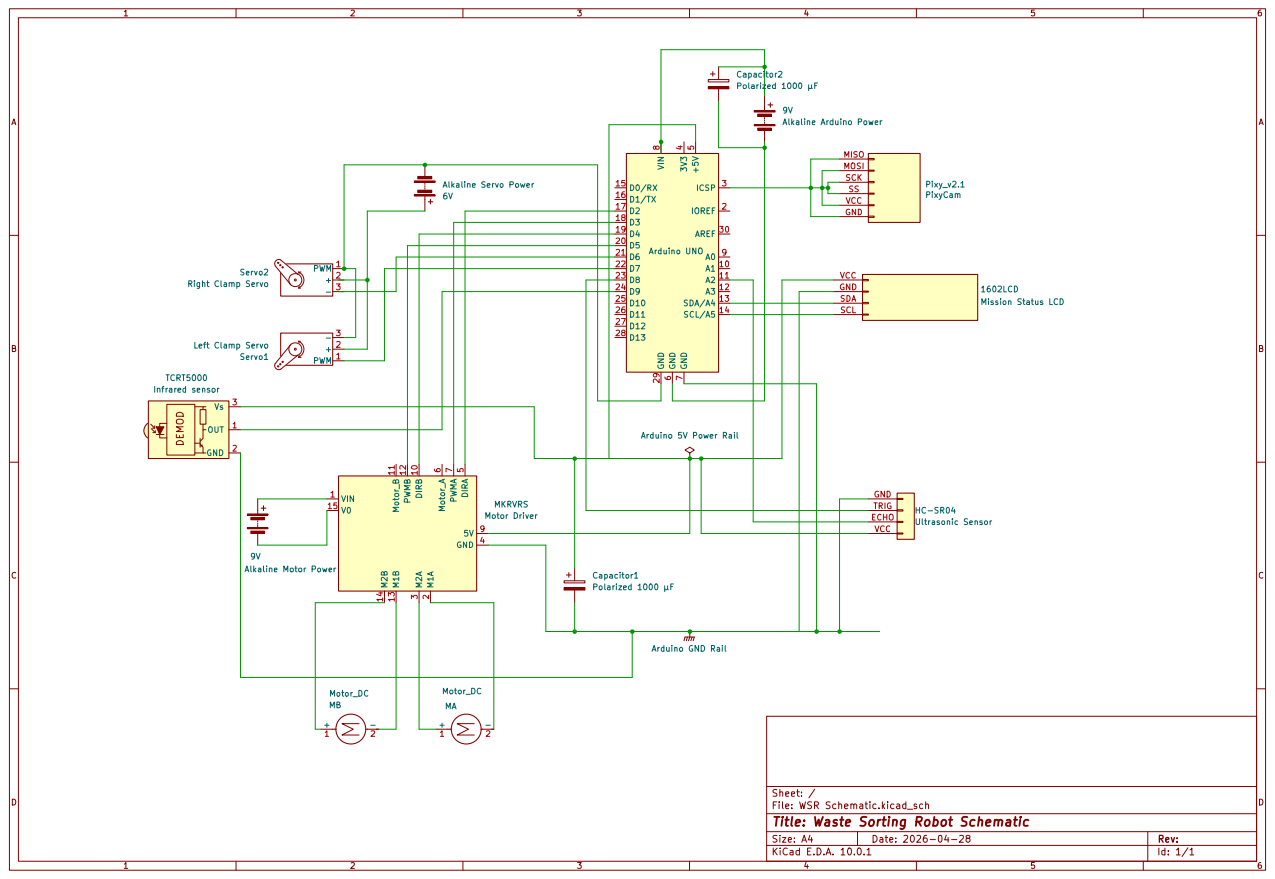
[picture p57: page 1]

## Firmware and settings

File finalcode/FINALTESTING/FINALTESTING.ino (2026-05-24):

#include <Pixy2.h>
#include <Servo.h>
#include <Wire.h>
#include <LiquidCrystal_I2C.h>

// ============================================================
// ---------------------- USER SETTINGS ------------------------
// ============================================================

// ---------- LCD ----------
#define LCD_ADDR 0x27
#define LCD_COLS 16
#define LCD_ROWS 2

// ---------- Pins ----------
const uint8_t DIR_A_PIN   = 2;
const uint8_t PWM_A_PIN   = 3;
const uint8_t DIR_B_PIN   = 4;
const uint8_t PWM_B_PIN   = 5;

const uint8_t SERVO_RIGHT_PIN = 6;   // user requested: right clamp on pin 6
const uint8_t SERVO_LEFT_PIN  = 7;   // user requested: left clamp on pin 7

const uint8_t ULTRASONIC_TRIG_PIN = 8;
const uint8_t IR_SENSOR_PIN       = 9;
const uint8_t ULTRASONIC_ECHO_PIN = A2;

const uint8_t LCD_SDA_PIN = A4;   // hardware I2C on Uno
const uint8_t LCD_SCL_PIN = A5;   // hardware I2C on Uno

// ---------- Servo angles ----------
const int SERVO_RIGHT_OPEN   = 0;    // pin 6
const int SERVO_RIGHT_CLOSED = 35;
const int SERVO_LEFT_OPEN    = 180;  // pin 7 (mirrored)
const int SERVO_LEFT_CLOSED  = 145;

// ---------- Pixy signatures ----------
const uint8_t SIG_RED    = 1;
const uint8_t SIG_GREEN  = 2;
const uint8_t SIG_BLUE   = 3;
const uint8_t SIG_BASE_1 = 4;  // orange
const uint8_t SIG_BASE_2 = 5;  // yellow
const uint8_t SIG_BASE_3 = 6;  // pink
const uint8_t SIG_BASE_4 = 7;  // purple

// ---------- Motion tuning ----------
const int TRAVEL_SPEED  = 100;
const int BASE_APPROACH = 90;
const int INCH_SPEED    = 70;
const int DEPOSIT_INCH_SPEED = 60;
const int DEPOSIT_PULLBACK_SPEED = INCH_SPEED;
const int TURN_SPEED    = 100;
const int CENTRE_SPEED  = 55;

// ---------- Turn timing ----------               v
const unsigned long TURN_180_MS = 1800;                 // user-specified
const unsigned long TURN_360_MS = TURN_180_MS * 1;      // derived
const unsigned long TURN_90_MS  = TURN_180_MS / 2;
const unsigned long POST_DEPOSIT_TURN_180_MS = TURN_180_MS;

// ---------- Ultrasonic / obstacle ----------
const int OBSTACLE_CM = 10;
const int ULTRA_TIMEOUT_US = 25000; // ~4m max
const uint8_t ULTRA_SAMPLES = 9;
const uint8_t ULTRA_SMOOTH_WINDOW = 3;
const unsigned long OBSTACLE_WAIT_CLEAR_MS = 3000;
const unsigned long OBSTACLE_REVERSE_MS = 320;
const unsigned long OBSTACLE_FORWARD_AFTER_TURN_MS = 1000;
const unsigned long DEPOSIT_INCH_FORWARD_MS = 3000;
const float BASE_DEPOSIT_CM = 4.0f;
const unsigned long BASE_DEPOSIT_TIMEOUT_MS = 7000;

// ---------- Pixy tuning ----------
const int PIXY_FRAME_CENTER_X = 158;  // approx center of Pixy2 316px width
const int CENTER_DEADBAND     = 12;   // centered if abs(error) <= this
const int CENTER_LOCK_FRAMES  = 5;    // how many centered frames before "locked"
const float STEER_KP          = 0.45; // proportional steering gain

// ---------- Search timing ----------
const unsigned long SEARCH_FORWARD_TIMEOUT_MS = 13000; // 10-15 seconds target
const unsigned long SEARCH_SWEEP_INTERVAL_MS  = 2600;
const unsigned long SEARCH_FORWARD_STEP_MS    = 900;
const unsigned long SEARCH_FORWARD_SLICE_MS   = 60;
const unsigned long POST_TURN_PUSH_MS         = 900;
const unsigned long CHASE_TIMEOUT_MS          = 25000;
const unsigned long RETURN_TIMEOUT_MS         = 25000;
const unsigned long BASE_LOG_TIMEOUT_MS       = 3000;
const unsigned long CENTER_TIMEOUT_MS         = 4000;
const unsigned long LOST_REACQUIRE_TIMEOUT_MS = 3500;
const unsigned long REVERSE_AFTER_DEPOSIT_MS = 2000;
const unsigned long STARTUP_REVERSE_MS = 2000;
const unsigned long SWEEP_CONFIRM_MS = 180;

// ---------- Base-size stop tuning ----------
// Robot stops when returned base appears close enough to startup view.
// Ratios below are intentionally a bit forgiving due to camera jitter.
const float BASE_WIDTH_RATIO_STOP  = 0.95;
const float BASE_HEIGHT_RATIO_STOP = 0.95;
const float BASE_AREA_RATIO_STOP   = 0.90;

// ---------- Misc ----------
const bool LEFT_FORWARD_DIR  = HIGH;
const bool LEFT_BACKWARD_DIR = LOW;
const bool RIGHT_FORWARD_DIR  = HIGH;
const bool RIGHT_BACKWARD_DIR = LOW;

// ============================================================
// ------------------- GLOBAL OBJECTS/STATE --------------------
// ============================================================

Pixy2 pixy;
Servo servoRight;
Servo servoLeft;
LiquidCrystal_I2C lcd(LCD_ADDR, LCD_COLS, LCD_ROWS);

struct BlockInfo
{
  bool valid;
  uint8_t sig;
  int x;
  int y;
  int w;
  int h;
  long area;
};

uint8_t loggedBaseSignature = 0;
int loggedBaseWidth = 0;
int loggedBaseHeight = 0;
long loggedBaseArea = 0;
bool pixyPausedForUltrasonic = false;
bool isFacingArena = false;

bool fullSweep360UntilFound(uint8_t targetSig, const char* label, bool suppressObstacleBecauseTargetIsBase);
bool confirmSignatureVisible(uint8_t targetSig, unsigned long confirmMs);

// ============================================================
// ----------------------- LCD HELPERS -------------------------
// ============================================================

void lcdPrint2(const char *line1, const char *line2)
{
  lcd.clear();
  lcd.setCursor(0, 0);
  lcd.print(line1);
  lcd.setCursor(0, 1);
  lcd.print(line2);
}

void lcdPrintSigLogged(uint8_t sig)
{
  lcd.clear();
  lcd.setCursor(0, 0);
  lcd.print("Base logged:");
  lcd.setCursor(0, 1);
  lcd.print(signatureName(sig));
}

const char* signatureName(uint8_t sig)
{
  switch (sig)
  {
    case SIG_RED:    return "RED (1)";
    case SIG_GREEN:  return "GREEN (2)";
    case SIG_BLUE:   return "BLUE (3)";
    case SIG_BASE_1: return "ORANGE (4)";
    case SIG_BASE_2: return "YELLOW (5)";
    case SIG_BASE_3: return "PINK (6)";
    case SIG_BASE_4: return "PURPLE (7)";
    default:         return "UNKNOWN";
  }
}

void setPixyPaused(bool paused)
{
  pixyPausedForUltrasonic = paused;

  // Force the Pixy lamp permanently OFF.
  // If setLamp is unsupported by firmware, behaviour degrades safely.
  pixy.setLamp(0, 0);
}

// ============================================================
// ---------------------- CLAMP CONTROL ------------------------
// ============================================================

void openClamp()
{
  servoRight.write(SERVO_RIGHT_OPEN);
  servoLeft.write(SERVO_LEFT_OPEN);
  delay(350);
}

void closeClamp()
{
  servoRight.write(SERVO_RIGHT_CLOSED);
  servoLeft.write(SERVO_LEFT_CLOSED);
  delay(350);
}

bool ballInClamp()
{
  // user specified: IR detects object in clamp
  // most FC-51 style outputs LOW on detect
  return (digitalRead(IR_SENSOR_PIN) == LOW);
}

// ============================================================
// ---------------------- MOTOR CONTROL ------------------------
// ============================================================

void setMotorOutputs(bool dirA, int pwmA, bool dirB, int pwmB)
{
  digitalWrite(DIR_A_PIN, dirA);
  digitalWrite(DIR_B_PIN, dirB);
  analogWrite(PWM_A_PIN, constrain(pwmA, 0, 255));
  analogWrite(PWM_B_PIN, constrain(pwmB, 0, 255));
}

void stopMotors()
{
  analogWrite(PWM_A_PIN, 0);
  analogWrite(PWM_B_PIN, 0);
}

void driveForward(int pwm)
{
  setMotorOutputs(LEFT_FORWARD_DIR, pwm, RIGHT_FORWARD_DIR, pwm);
}

void driveBackward(int pwm)
{
  setMotorOutputs(LEFT_BACKWARD_DIR, pwm, RIGHT_BACKWARD_DIR, pwm);
}

void spinRight(int pwm)
{
  // in-place rotate right
  setMotorOutputs(LEFT_FORWARD_DIR, pwm, RIGHT_BACKWARD_DIR, pwm);
}

void spinLeft(int pwm)
{
  // in-place rotate left
  setMotorOutputs(LEFT_BACKWARD_DIR, pwm, RIGHT_FORWARD_DIR, pwm);
}

void steerForward(int leftPwm, int rightPwm)
{
  setMotorOutputs(LEFT_FORWARD_DIR, leftPwm, RIGHT_FORWARD_DIR, rightPwm);
}

void reverseBriefly(int pwm, unsigned long ms)
{
  driveBackward(pwm);
  delay(ms);
  stopMotors();
}

void timedTurn(bool turnRightDirection, unsigned long durationMs, int pwm, bool showLCD, const char* lcdLine2)
{
  if (showLCD)
  {
    lcdPrint2("Turning", lcdLine2);
  }

  unsigned long start = millis();
  while (millis() - start < durationMs)
  {
    if (turnRightDirection)
      spinRight(pwm);
    else
      spinLeft(pwm);

    delay(10);
  }
  stopMotors();
}

// ============================================================
// ------------------- ULTRASONIC / FILTER ---------------------
// ============================================================

float readUltrasonicCmRawPrecise()
{
  digitalWrite(ULTRASONIC_TRIG_PIN, LOW);
  delayMicroseconds(2);
  digitalWrite(ULTRASONIC_TRIG_PIN, HIGH);
  delayMicroseconds(10);
  digitalWrite(ULTRASONIC_TRIG_PIN, LOW);

  unsigned long duration = pulseIn(ULTRASONIC_ECHO_PIN, HIGH, ULTRA_TIMEOUT_US);
  if (duration == 0)
  {
    return 400.0f; // no echo -> treat as far away
  }

  float distanceCm = duration * 0.0343f / 2.0f;
  return distanceCm;
}

int readUltrasonicCmRaw()
{
  float distanceCm = readUltrasonicCmRawPrecise();
  return (int)distanceCm;
}

float medianOfArray(float *values, uint8_t count)
{
  for (uint8_t i = 0; i < count - 1; i++)
  {
    for (uint8_t j = 0; j < count - 1 - i; j++)
    {
      if (values[j] > values[j + 1])
      {
        float temp = values[j];
        values[j] = values[j + 1];
        values[j + 1] = temp;
      }
    }
  }

  return values[count / 2];
}

float medianDistanceCmPrecise()
{
  // Stage 1: burst median
  float readings[ULTRA_SAMPLES];
  for (uint8_t i = 0; i < ULTRA_SAMPLES; i++)
  {
    readings[i] = readUltrasonicCmRawPrecise();
    delay(random(8, 18)); // slight jitter reduces sync/crosstalk effects
  }
  float burstMedian = medianOfArray(readings, ULTRA_SAMPLES);

  // Stage 2: rolling median over recent burst medians
  static float history[ULTRA_SMOOTH_WINDOW];
  static uint8_t historyCount = 0;
  static uint8_t historyIndex = 0;

  history[historyIndex] = burstMedian;
  historyIndex = (historyIndex + 1) % ULTRA_SMOOTH_WINDOW;
  if (historyCount < ULTRA_SMOOTH_WINDOW)
    historyCount++;

  float temp[ULTRA_SMOOTH_WINDOW];
  for (uint8_t i = 0; i < historyCount; i++)
    temp[i] = history[i];

  return medianOfArray(temp, historyCount);
}

int medianDistanceCm()
{
  return (int)medianDistanceCmPrecise();
}

// IMPORTANT:
// During initial base logging and final base homing, the robot is intentionally
// facing / approaching the base. In those moments the home base itself would
// appear as an "obstacle" to the front ultrasonic sensor. So obstacle avoidance
// is bypassed only during those phases.
bool avoidObstacleIfNeeded(bool suppressBecauseTargetIsBase, uint8_t rescanSig = 0, const char* rescanLabel = "", bool allowRescan = true)
{
  if (suppressBecauseTargetIsBase)
  {
    return false;
  }

  int d = medianDistanceCm();
  if (d > OBSTACLE_CM)
  {
    return false;
  }

  stopMotors();
  lcdPrint2("Obstacle <=10cm", "Wait 3 sec");

  unsigned long waitStart = millis();
  while (millis() - waitStart < OBSTACLE_WAIT_CLEAR_MS)
  {
    delay(110);
    d = medianDistanceCm();
    if (d > OBSTACLE_CM)
    {
      stopMotors();
      delay(80);
      return true;
    }
  }

  // If still blocked after 3s, back up slightly.
  lcdPrint2("Obstacle stuck", "Reverse a bit");
  reverseBriefly(INCH_SPEED, OBSTACLE_REVERSE_MS);
  delay(80);

  // Then run a 360 sweep for the desired signature.
  bool foundDuringSweep = false;
  if (allowRescan && rescanSig != 0)
  {
    lcdPrint2("Obstacle scan", "360 target");
    unsigned long scanStart = millis();
    while (millis() - scanStart < TURN_360_MS + 300)
    {
      spinRight(TURN_SPEED);

      BlockInfo b;
      if (getLargestBlockBySignature(rescanSig, b))
      {
        stopMotors();
        if (confirmSignatureVisible(rescanSig, SWEEP_CONFIRM_MS))
        {
          foundDuringSweep = true;
          break;
        }
      }

      delay(25);
    }
    stopMotors();
  }

  if (foundDuringSweep)
  {
    return true;
  }

  // Not found: from original heading, turn 180 and move forward a bit.
  lcdPrint2("No target", "Turn 180");
  timedTurn(true, TURN_180_MS, TURN_SPEED, false, "");
  delay(120);

  lcdPrint2("Resume search", "Forward bit");
  driveForward(TRAVEL_SPEED);
  delay(OBSTACLE_FORWARD_AFTER_TURN_MS);
  stopMotors();
  delay(120);

  return true;
}

// ============================================================
// ----------------------- PIXY HELPERS ------------------------
// ============================================================

bool isBaseSignature(uint8_t sig)
{
  return (sig == SIG_BASE_1 || sig == SIG_BASE_2 || sig == SIG_BASE_3 || sig == SIG_BASE_4);
}

bool getLargestBlockBySignature(uint8_t signature, BlockInfo &out)
{
  out.valid = false;
  if (pixyPausedForUltrasonic)
    return false;

  uint16_t numBlocks = pixy.ccc.getBlocks();
  if (numBlocks == 0)
    return false;

  long bestArea = -1;

  for (uint16_t i = 0; i < numBlocks; i++)
  {
    auto &b = pixy.ccc.blocks[i];
    if (b.m_signature != signature)
      continue;

    long area = (long)b.m_width * (long)b.m_height;
    if (area > bestArea)
    {
      bestArea = area;
      out.valid = true;
      out.sig = b.m_signature;
      out.x = b.m_x;
      out.y = b.m_y;
      out.w = b.m_width;
      out.h = b.m_height;
      out.area = area;
    }
  }

  return out.valid;
}

bool getLargestBaseBlock(BlockInfo &out)
{
  out.valid = false;
  if (pixyPausedForUltrasonic)
    return false;

  uint16_t numBlocks = pixy.ccc.getBlocks();
  if (numBlocks == 0)
    return false;

  long bestArea = -1;

  for (uint16_t i = 0; i < numBlocks; i++)
  {
    auto &b = pixy.ccc.blocks[i];
    if (!isBaseSignature(b.m_signature))
      continue;

    long area = (long)b.m_width * (long)b.m_height;
    if (area > bestArea)
    {
      bestArea = area;
      out.valid = true;
      out.sig = b.m_signature;
      out.x = b.m_x;
      out.y = b.m_y;
      out.w = b.m_width;
      out.h = b.m_height;
      out.area = area;
    }
  }

  return out.valid;
}

// ============================================================
// -------------------- BASE LOG / RETURN ----------------------
// ============================================================

bool logBaseSignatureAtStart()
{
  lcdPrint2("Starting WALL-F", "Scan base...");
  unsigned long start = millis();

  BlockInfo best;
  best.valid = false;
  best.area = -1;

  while (millis() - start < BASE_LOG_TIMEOUT_MS)
  {
    BlockInfo current;
    if (getLargestBaseBlock(current))
    {
      if (!best.valid || current.area > best.area)
      {
        best = current;
      }
    }
    delay(35);
  }

  if (!best.valid)
  {
    lcdPrint2("Base scan fail", "No signature");
    return false;
  }

  loggedBaseSignature = best.sig;
  loggedBaseWidth = best.w;
  loggedBaseHeight = best.h;
  loggedBaseArea = best.area;

  lcdPrintSigLogged(loggedBaseSignature);
  delay(1200);

  lcd.clear();
  lcd.setCursor(0, 0);
  lcd.print("Base size:");
  lcd.setCursor(0, 1);
  lcd.print(best.w);
  lcd.print("x");
  lcd.print(best.h);
  delay(1200);

  return true;
}

bool reachedHomeSize(const BlockInfo &b)
{
  bool widthReached  = (b.w >= (int)(loggedBaseWidth  * BASE_WIDTH_RATIO_STOP));
  bool heightReached = (b.h >= (int)(loggedBaseHeight * BASE_HEIGHT_RATIO_STOP));
  bool areaReached   = (b.area >= (long)(loggedBaseArea * BASE_AREA_RATIO_STOP));

  // Require either both dimensions, or area as backup.
  return ((widthReached && heightReached) || areaReached);
}

bool centerOnSignature(uint8_t targetSig, const char* label, unsigned long timeoutMs, bool suppressObstacleBecauseTargetIsBase)
{
  lcdPrint2("Centering", label);

  unsigned long start = millis();
  uint8_t lockedFrames = 0;
  int lastError = 0;

  while (millis() - start < timeoutMs)
  {
    if (avoidObstacleIfNeeded(suppressObstacleBecauseTargetIsBase, targetSig, label, true))
    {
      lockedFrames = 0;
      continue;
    }

    BlockInfo b;
    if (getLargestBlockBySignature(targetSig, b))
    {
      int error = b.x - PIXY_FRAME_CENTER_X;
      lastError = error;

      if (abs(error) <= CENTER_DEADBAND)
      {
        stopMotors();
        lockedFrames++;
        if (lockedFrames >= CENTER_LOCK_FRAMES)
        {
          stopMotors();
          return true;
        }
      }
      else
      {
        lockedFrames = 0;
        int turnPwm = constrain(CENTRE_SPEED + abs(error) / 4, 40, 110);

        if (error > 0)
          spinRight(turnPwm);
        else
          spinLeft(turnPwm);
      }
    }
    else
    {
      lockedFrames = 0;
      if (lastError >= 0)
        spinRight(CENTRE_SPEED);
      else
        spinLeft(CENTRE_SPEED);
    }

    delay(35);
  }

  stopMotors();
  return false;
}

bool confirmSignatureVisible(uint8_t targetSig, unsigned long confirmMs)
{
  unsigned long start = millis();
  while (millis() - start < confirmMs)
  {
    BlockInfo b;
    if (!getLargestBlockBySignature(targetSig, b))
      return false;
    delay(20);
  }
  return true;
}

bool timedSpinUntilFound(uint8_t targetSig, bool turnRightDirection, unsigned long durationMs, const char* lcdLine2)
{
  lcdPrint2("Scanning", lcdLine2);

  unsigned long start = millis();
  while (millis() - start < durationMs)
  {
    if (avoidObstacleIfNeeded(false, targetSig, lcdLine2, true))
    {
      start = millis();
      continue;
    }

    if (turnRightDirection)
      spinRight(TURN_SPEED);
    else
      spinLeft(TURN_SPEED);

    BlockInfo b;
    if (getLargestBlockBySignature(targetSig, b))
    {
      stopMotors();
      if (confirmSignatureVisible(targetSig, SWEEP_CONFIRM_MS))
      {
        return true;
      }
    }

    delay(25);
  }

  stopMotors();
  return false;
}

void timedSpinNoSearch(bool turnRightDirection, unsigned long durationMs, const char* lcdLine2)
{
  lcdPrint2("Turning", lcdLine2);

  unsigned long start = millis();
  while (millis() - start < durationMs)
  {
    if (turnRightDirection)
      spinRight(TURN_SPEED);
    else
      spinLeft(TURN_SPEED);

    delay(25);
  }

  stopMotors();
}

bool sweep180Search(uint8_t targetSig, const char* label)
{
  // Right 90 deg
  if (timedSpinUntilFound(targetSig, true, TURN_90_MS, label))
    return true;

  // Left 180 deg
  if (timedSpinUntilFound(targetSig, false, TURN_180_MS, label))
    return true;

  // Return to original heading: Right 90 deg
  timedSpinNoSearch(true, TURN_90_MS, label);
  return false;
}

bool fullSweep360UntilFound(uint8_t targetSig, const char* label, bool suppressObstacleBecauseTargetIsBase)
{
  lcdPrint2("360 sweep", label);
  unsigned long start = millis();

  while (millis() - start < TURN_360_MS + 300)
  {
    avoidObstacleIfNeeded(suppressObstacleBecauseTargetIsBase, targetSig, label, true);
    spinRight(TURN_SPEED);

    BlockInfo b;
    if (getLargestBlockBySignature(targetSig, b))
    {
      stopMotors();
      if (confirmSignatureVisible(targetSig, SWEEP_CONFIRM_MS))
      {
        return true;
      }
    }

    delay(25);
  }

  stopMotors();
  return false;
}

// ============================================================
// -------------------- BALL SEARCH / CHASE --------------------
// ============================================================

bool searchForBall(uint8_t targetSig, const char* label)
{
  // First check if already in view
  BlockInfo b;
  if (getLargestBlockBySignature(targetSig, b))
  {
    stopMotors();
    return true;
  }

  lcdPrint2("Search mode", "Forward bias");
  unsigned long start = millis();
  unsigned long lastSweep = millis();
  uint8_t missedSweeps = 0;

  while (millis() - start < SEARCH_FORWARD_TIMEOUT_MS)
  {
    if (avoidObstacleIfNeeded(false, targetSig, label, true))
    {
      lastSweep = millis();
      continue;
    }

    // If ball appears, stop immediately
    if (getLargestBlockBySignature(targetSig, b))
    {
      stopMotors();
      return true;
    }

    lcdPrint2("Searching", "Drive forward");
    unsigned long stepStart = millis();
    while ((millis() - stepStart < SEARCH_FORWARD_STEP_MS) && (millis() - start < SEARCH_FORWARD_TIMEOUT_MS))
    {
      if (avoidObstacleIfNeeded(false, targetSig, label, true))
      {
        lastSweep = millis();
        break;
      }

      if (getLargestBlockBySignature(targetSig, b))
      {
        stopMotors();
        return true;
      }

      driveForward(TRAVEL_SPEED);
      delay(SEARCH_FORWARD_SLICE_MS);
    }

    stopMotors();
    delay(60);

    if (getLargestBlockBySignature(targetSig, b))
    {
      stopMotors();
      return true;
    }

    if (millis() - lastSweep >= SEARCH_SWEEP_INTERVAL_MS)
    {
      lcdPrint2("Search sweep", "180 deg");
      if (sweep180Search(targetSig, label))
      {
        stopMotors();
        return true;
      }

      lastSweep = millis();
      missedSweeps++;
      if (missedSweeps >= 2)
      {
        lcdPrint2("Search sweep", "360 recover");
        if (fullSweep360UntilFound(targetSig, label, false))
        {
          stopMotors();
          return true;
        }
        missedSweeps = 0;
      }
    }
  }

  stopMotors();
  return false;
}
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
void loop()
{
  // Infinite strict order: RED -> GREEN -> BLUE -> repeat forever
  doOneColourCycle(SIG_RED,   "RED");
  doOneColourCycle(SIG_GREEN, "GREEN");
  doOneColourCycle(SIG_BLUE,  "BLUE");
}

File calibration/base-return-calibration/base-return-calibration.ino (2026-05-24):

#include <Pixy2.h>

Pixy2 pixy;

// Replace xxxx with the base signature being measured.
const uint8_t TEST_BASE_SIGNATURE = xxxx;

// Replace xxxx after measuring the base from the startup distance.
const int LOGGED_BASE_WIDTH = xxxx;
const int LOGGED_BASE_HEIGHT = xxxx;
const long LOGGED_BASE_AREA = xxxx;

// Replace xxxx after testing return stopping behaviour.
const float BASE_WIDTH_RATIO_STOP = xxxx;
const float BASE_HEIGHT_RATIO_STOP = xxxx;
const float BASE_AREA_RATIO_STOP = xxxx;

void setup()
{
  Serial.begin(115200);
  pixy.init();
  pixy.setLamp(0, 0);
}

void loop()
{
  uint16_t blocks = pixy.ccc.getBlocks();
  bool found = false;

  for (uint16_t i = 0; i < blocks; i++)
  {
    if (pixy.ccc.blocks[i].m_signature != TEST_BASE_SIGNATURE)
    {
      continue;
    }

    int w = pixy.ccc.blocks[i].m_width;
    int h = pixy.ccc.blocks[i].m_height;
    long area = (long)w * (long)h;

    bool widthReached = w >= (int)(LOGGED_BASE_WIDTH * BASE_WIDTH_RATIO_STOP);
    bool heightReached = h >= (int)(LOGGED_BASE_HEIGHT * BASE_HEIGHT_RATIO_STOP);
    bool areaReached = area >= (long)(LOGGED_BASE_AREA * BASE_AREA_RATIO_STOP);

    Serial.print("base w=");
    Serial.print(w);
    Serial.print(" h=");
    Serial.print(h);
    Serial.print(" area=");
    Serial.print(area);
    Serial.print(" reached=");
    Serial.println((widthReached && heightReached) || areaReached ? "YES" : "NO");

    found = true;
  }

  if (!found)
  {
    Serial.println("base not visible");
  }

  delay(250);
}

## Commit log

2026-05-26 Polish schematic and asset documentation
2026-05-27 Polish Wall-F README and schematic docs
2026-05-29 Document current hardware documentation focus
2026-05-29 Add KiCad schematic source files
    [WALL-F.kicad_sch, WSR Schematic.kicad_sch]
